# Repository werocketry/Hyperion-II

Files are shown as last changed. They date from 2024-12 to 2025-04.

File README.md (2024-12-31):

# Hyperion-II

This repository contains all the resources, designs, and analyses for the Hyperion-II rocket project. It is organized into several folders, each dedicated to a specific aspect of the project. Below is a breakdown of the repository structure and its contents.

## Repository Details

Click [here](DSS.md) to see the design summary sheet!

### Structure

```
Hyperion-II
├───cad
│   └───dwg
├───ork
│   └───outputs
├───rasAeroII
├───schematics
└───testing
   └───aero
```

### `cad/`

Contains the computer-aided design (CAD) files for Hyperion-II, including drawings and 3D models. The `dwg/` subfolder is specifically for detailed technical drawings.

### `ork/`

Holds all OpenRocket simulation files (`.ork`) and associated Python scripts that utilize [orlab](https://github.com/CameronBrooks11/orlab) for simulation analysis. The `outputs/` subfolder contains generated plots, text files, and sensitivity analyses derived from these simulations. Once you have Python and a valid Java release installed, install `orlab` using:

```
pip install orlab
```

For detailed installation instructions see [CameronBrooks11/orlab](https://github.com/CameronBrooks11/orlab).

### `rasAeroII/`

Placeholder for files related to RASAero II simulations.

### `schematics/`

Contains electronic schematics and related documentation for onboard systems.

### `testing/`

Documents all physical tests, including aerodynamics, electronics, and structural assessments. Each test has its own subfolder with details and results.

- **Key Subfolders**:
  - `2024-11-24_compression_al_couplers/`: Contains data for aluminum coupler compression testing on the specified date.

## Contributing

Contributions are welcome! Please fork the repository, make your changes, and submit a pull request. Ensure you adhere to the coding standards and provide detailed documentation for any new scripts or analyses.

## License

This project is licensed under the terms of the [MIT License](LICENSE).

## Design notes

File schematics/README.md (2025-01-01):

# schematics

This is where the source files and most recent exports will be stored and historical export versions on teams.

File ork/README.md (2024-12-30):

# ork

This is where our OpenRocket simulations go. The `.py` scripts leverage [orlab](https://github.com/CameronBrooks11/orlab) to run OpenRocket via Python. Doing this allows us to build and test our rocket using the OpenRocket application GUI, then use code to automate and enhance the analysis.

By scripting with `orlab`, we can:

- Run simulations programmatically, enabling batch testing and parameter sweeps.
- Extract detailed flight data and events for further processing.
- Generate custom plots and outputs that are not natively available in OpenRocket.
- Integrate OpenRocket data into larger workflows or other engineering tools.

The `outputs` folder contains images and text files generated by the scripts, including:

- Flight performance plots such as thrust, velocity, and altitude over time.
- Key metrics like rail exit velocity, average descent velocities, and ground impact conditions.
- Summarized event logs detailing critical moments in the flight, such as apogee, recovery deployments, and ground hit.

This approach ensures that we can efficiently analyze and refine our rocket designs while keeping a comprehensive record of simulation results for future reference.

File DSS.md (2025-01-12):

# Design Summary Sheet

This document outlines the design and components of the rocket, organized by subteam and section, detailing the contributions of each.

## By Subteam

- **Aero**

  - Nose cone (88cm)
    - COTS 14cm (5.5") diameter, 5.5:1 Von Karman, fibreglass
      - Machined aluminium tip
      - [madcowrocketry - 5.5 nose cone with metal tip](https://www.madcowrocketry.com/fiberglass-5-5-filament-wound-metal-tip-select-shape/)
      - Length of curvature 74cm + length of flat portion 14cm
  - CF Tubes
    - Main chute bay tube (39cm)
    - Airbrakes/drogue chute bay tube (56cm)
    - Engine tube (61cm)
  - Fibreglass tubes
    - Avionics bay tube (33cm)
    - For areas that require RF permeability
  - Aluminum Bulkheads
    - Diameter 13.244cm
    - Thickness 1.5cm
  - Fins
    - Tip to tip attachment
    - Fins made using a composite sandwich:
      - Foam core as the inner base
      - Intermediate layers of glass fibre
      - Outer layers of carbon fibre
    - Specifications:
      - Root chord: 33.1cm
      - Tip chord: 13.95cm
      - Span: 13.5cm
      - Sweep angle: 35.35 degrees

- **Airbrakes**

  - Airbrakes flaps cut from body tube
    - 3 flaps extending radially
    - Flaps mounted on PETG supports with fore edge on a hinge and the aft edge connected to PETG push rod
    - Lead screw driven by DC motor actuates push rods
    - DC motor with gearbox operated using custom flight controller powered by 18650 Li-ion cells

- **Avionics**

  - Dual deployment with redundant electronics
    - Primary: Featherweight Blue Raven + Featherweight GPS
    - Redundant: Altus Metrum Telemega (integrated GPS)
  - Two-sided "sled" style avionics bay made of polycarbonate sheets and 3D printed PETG parts

- **Payload**

  - 3U Payload
    - 9.6cm x 9.6cm x 30cm
      - Needs to be undersized from 10cm profile to fit existing nosecone
    - CubeSat form factor frame made from aluminium
    - Contains the SRAD flight computer
    - Ballast to reach target mass (inert, possibly a pioreactor)
    - 4000g (8.818lbs) (subject to change)

- **Propulsion**

  - 3G 96mm CTI hardware
    - M2505 as chosen reload
      - Performance: Total impulse of 7450.00 N·s, average thrust of 2491.02 N, and maximum thrust of 2952.61 N over a 3.00-second burn time
      - Specifications: Dimensions of 98.0 mm x 579.0 mm, with a propellant mass of 3.339 kg and casing mass of 2.866 kg
      - Ignition System: Dual-headed boron igniter
    - Alternatives: M1290, M1520

- **Recovery**
  - Main chute
    - 244cm (96") ripstop nylon main chute
      - Six 30cm shroud lines
  - Drogue chute
    - 61cm (24") ripstop nylon drogue chute
      - Six 30cm shroud lines
  - Kevlar shock cords

## By Section

- **Nose cone (88cm)**

  - COTS 14cm (5.5") diameter, 5.5:1 Von Karman, fibreglass
    - Machined aluminium tip
    - [madcowrocketry - 5.5 nose cone with metal tip](https://www.madcowrocketry.com/fiberglass-5-5-filament-wound-metal-tip-select-shape/)
    - Length of curvature 74cm + length of flat portion 14cm
  - 3U Payload
    - 9.6cm x 9.6cm x 30cm
    - CubeSat form factor frame made from aluminium
    - Contains SRAD flight computer and ballast
    - 4000g (8.818lbs)
  - Aluminum Bulkhead
    - Diameter 13.244cm
    - Thickness 1.5cm

- **Main chute bay (39cm)**

  - Carbon fibre tube
  - 244cm (96") ripstop nylon main chute
    - Six 30cm shroud lines

- **Avionics bay (33cm)**

  - Fibreglass tube (chosen over CF for RF permeability)
  - Dual deployment with redundant electronics
    - Primary: Featherweight Blue Raven + Featherweight GPS
    - Redundant: Altus Metrum Telemega (integrated GPS)

- **Airbrakes - drogue chute bay (56cm)**

  - Carbon fibre tube
  - 61cm (24") ripstop nylon drogue chute
    - Six 30cm shroud lines
  - Airbrakes flaps cut from body tube
    - 3 flaps extending radially
    - Flaps mounted on PETG supports with fore edge on a hinge and the aft edge connected to PETG push rod
    - Lead screw driven by DC motor actuates push rods
    - DC motor operated using custom flight controller powered by 18650 Li-ion cells

- **Engine tube (61cm)**
  - Carbon fibre tube
  - 3G 96mm CTI hardware
    - M2505 as chosen reload
      - Performance: Total impulse of 7450.00 N·s, average thrust of 2491.02 N, and maximum thrust of 2952.61 N over a 3.00-second burn time
      - Specifications: Dimensions of 98.0 mm x 579.0 mm, with a propellant mass of 3.339 kg and casing mass of 2.866 kg
      - Ignition System: Dual-headed boron igniter
      - Alternatives: M1290, M1520
  - Tip to tip attachment of fins
    - Fins made using a composite sandwich consisting of foam core as the inner base followed by intermediate layers of glass fibre followed by outer layers of carbon fibre
    - Specifications: Root chord of 33.1cm, tip chord of 13.95cm, span of 13.5cm, and sweep angle of 35.35 degrees

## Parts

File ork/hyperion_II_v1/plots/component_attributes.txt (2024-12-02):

List of all components with their attributes:

Component 1:
  Name: HyperionIIV1
  Type: Rocket
  Mass: 0.0 kg
  Length: 2.7974218000000004 m
  Diameter: Not Available
  Reference Area: Not Available

--------------------------------------------------

Component 2:
  Name: Sustainer
  Type: AxialStage
  Mass: 0.0 kg
  Length: 2.7720218 m
  Diameter: Not Available
  Reference Area: Not Available

--------------------------------------------------

Component 3:
  Name: Nose Cone
  Type: NoseCone
  Mass: 0.636 kg
  Length: 0.742 m
  Diameter: Not Available
  Reference Area: Not Available

--------------------------------------------------

Component 4:
  Name: Nosecone - Flat Portion
  Type: BodyTube
  Mass: 0.3 kg
  Length: 0.1397 m
  Diameter: Not Available
  Reference Area: Not Available

--------------------------------------------------

Component 5:
  Name: Payload
  Type: MassComponent
  Mass: 3.992 kg
  Length: 0.3 m
  Diameter: Not Available
  Reference Area: Not Available

--------------------------------------------------

Component 6:
  Name: Main Chute Bay
  Type: BodyTube
  Mass: 0.335 kg
  Length: 0.39032179999999994 m
  Diameter: Not Available
  Reference Area: Not Available

--------------------------------------------------

Component 7:
  Name: Nosecone-Main Coupler
  Type: TubeCoupler
  Mass: 0.312 kg
  Length: 0.28 m
  Diameter: Not Available
  Reference Area: Not Available

--------------------------------------------------

Component 8:
  Name: Nosecone-Main Bulkhead
  Type: Bulkhead
  Mass: 0.5535 kg
  Length: 0.015 m
  Diameter: Not Available
  Reference Area: Not Available

--------------------------------------------------

Component 9:
  Name: Main Parachute
  Type: Parachute
  Mass: 1.044 kg
  Length: 0.2286 m
  Diameter: 2.4383999999999997 m
  Reference Area: Not Available

--------------------------------------------------

Component 10:
  Name: Deployable Payload
  Type: MassComponent
  Mass: 1.5 kg
  Length: 0.1 m
  Diameter: Not Available
  Reference Area: Not Available

--------------------------------------------------

Component 11:
  Name: Deployable Parachute
  Type: Parachute
  Mass: 0.377 kg
  Length: 0.115824 m
  Diameter: 0.6095999999999999 m
  Reference Area: Not Available

--------------------------------------------------

Component 12:
  Name: Av Bay Body Tube
  Type: BodyTube
  Mass: 0.28600000000000003 kg
  Length: 0.32799999999999996 m
  Diameter: Not Available
  Reference Area: Not Available

--------------------------------------------------

Component 13:
  Name: Avionics
  Type: MassComponent
  Mass: 0.77 kg
  Length: 0.298 m
  Diameter: Not Available
  Reference Area: Not Available

--------------------------------------------------

Component 14:
  Name: Main-Avionics Coupler
  Type: TubeCoupler
  Mass: 0.244 kg
  Length: 0.28 m
  Diameter: Not Available
  Reference Area: Not Available

--------------------------------------------------

Component 15:
  Name: Avionics-Main Bulkhead
  Type: Bulkhead
  Mass: 0.5535 kg
  Length: 0.015 m
  Diameter: Not Available
  Reference Area: Not Available

--------------------------------------------------

Component 16:
  Name: Airbrakes-Drogue Body Tube
  Type: BodyTube
  Mass: 0.359 kg
  Length: 0.56 m
  Diameter: Not Available
  Reference Area: Not Available

--------------------------------------------------

Component 17:
  Name: Avionics-Drogue Coupler
  Type: TubeCoupler
  Mass: 0.244 kg
  Length: 0.28 m
  Diameter: Not Available
  Reference Area: Not Available

--------------------------------------------------

Component 18:
  Name: Drogue-Avionics Bulkhead
  Type: Bulkhead
  Mass: 0.5535 kg
  Length: 0.015 m
  Diameter: Not Available
  Reference Area: Not Available

--------------------------------------------------

Component 19:
  Name: Drogue Parachute
  Type: Parachute
  Mass: 0.377 kg
  Length: 0.15239999999999998 m
  Diameter: 0.6095999999999999 m
  Reference Area: Not Available

--------------------------------------------------

Component 20:
  Name: Airbrakes-Drogue Bulkhead
  Type: Bulkhead
  Mass: 0.5967 kg
  Length: 0.015 m
  Diameter: Not Available
  Reference Area: Not Available

--------------------------------------------------

Component 21:
  Name: Airbrakes
  Type: MassComponent
  Mass: 0.663 kg
  Length: 0.23 m
  Diameter: Not Available
  Reference Area: Not Available

--------------------------------------------------

Component 22:
  Name: Additional Mass
  Type: MassComponent
  Mass: 1.0 kg
  Length: 0.025 m
  Diameter: Not Available
  Reference Area: Not Available

--------------------------------------------------

Component 23:
  Name: Engine Tube
  Type: BodyTube
  Mass: 0.733 kg
  Length: 0.612 m
  Diameter: Not Available
  Reference Area: Not Available

--------------------------------------------------

Component 24:
  Name: Airbrakes-Engine Coupler
  Type: TubeCoupler
  Mass: 0.312 kg
  Length: 0.32 m
  Diameter: Not Available
  Reference Area: Not Available

--------------------------------------------------

Component 25:
  Name: Engine Bulkhead
  Type: Bulkhead
  Mass: 0.5562 kg
  Length: 0.015 m
  Diameter: Not Available
  Reference Area: Not Available

--------------------------------------------------

Component 26:
  Name: Centering Ring
  Type: CenteringRing
  Mass: 0.029157624072791443 kg
  Length: 0.004762499999999999 m
  Diameter: Not Available
  Reference Area: Not Available

--------------------------------------------------

Component 27:
  Name: Centering Ring
  Type: CenteringRing
  Mass: 0.029157624072791443 kg
  Length: 0.004762499999999999 m
  Diameter: Not Available
  Reference Area: Not Available

--------------------------------------------------

Component 28:
  Name: Freeform fin set #1
  Type: FreeformFinSet
  Mass: 0.60946425 kg
  Length: 0.330708 m
  Diameter: Not Available
  Reference Area: Not Available

--------------------------------------------------

Component 29:
  Name: Inner Motor Tube
  Type: InnerTube
  Mass: 0.08746076137869509 kg
  Length: 0.55 m
  Diameter: Not Available
  Reference Area: Not Available

--------------------------------------------------

Component 30:
  Name: Launch lug
  Type: LaunchLug
  Mass: 0.0067 kg
  Length: 0.03 m
  Diameter: Not Available
  Reference Area: Not Available

--------------------------------------------------

Component 31:
  Name: Launch lug
  Type: LaunchLug
  Mass: 0.0067 kg
  Length: 0.03 m
  Diameter: Not Available
  Reference Area: Not Available

--------------------------------------------------

Component 32:
  Name: Thrust Plate
  Type: MassComponent
  Mass: 0.242 kg
  Length: 0.028575 m
  Diameter: Not Available
  Reference Area: Not Available

--------------------------------------------------

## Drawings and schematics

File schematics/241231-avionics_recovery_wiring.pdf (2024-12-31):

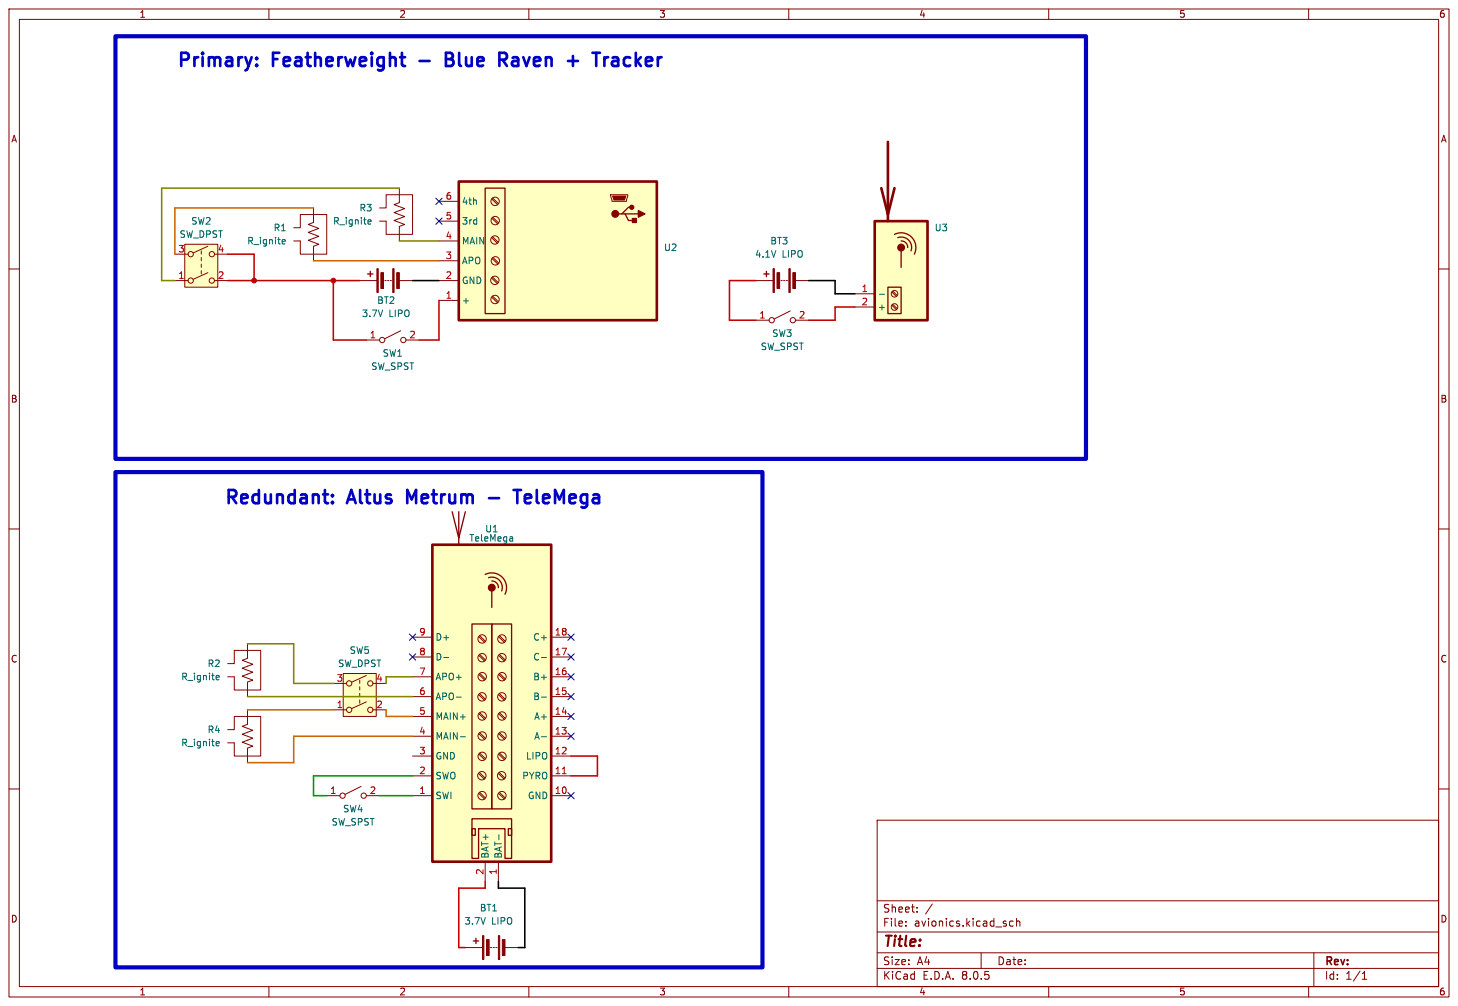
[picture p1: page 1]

2 SWO 2 GND 3 MAIN- 4 MAIN+ 5 APO- 6 APO+ 7 D- 8 D+ 9 U1 TeleMega R2 R_ignite BT1

Id: 1/1 Title: File: avionics.kicad_sch Sheet: / R4 R_ignite

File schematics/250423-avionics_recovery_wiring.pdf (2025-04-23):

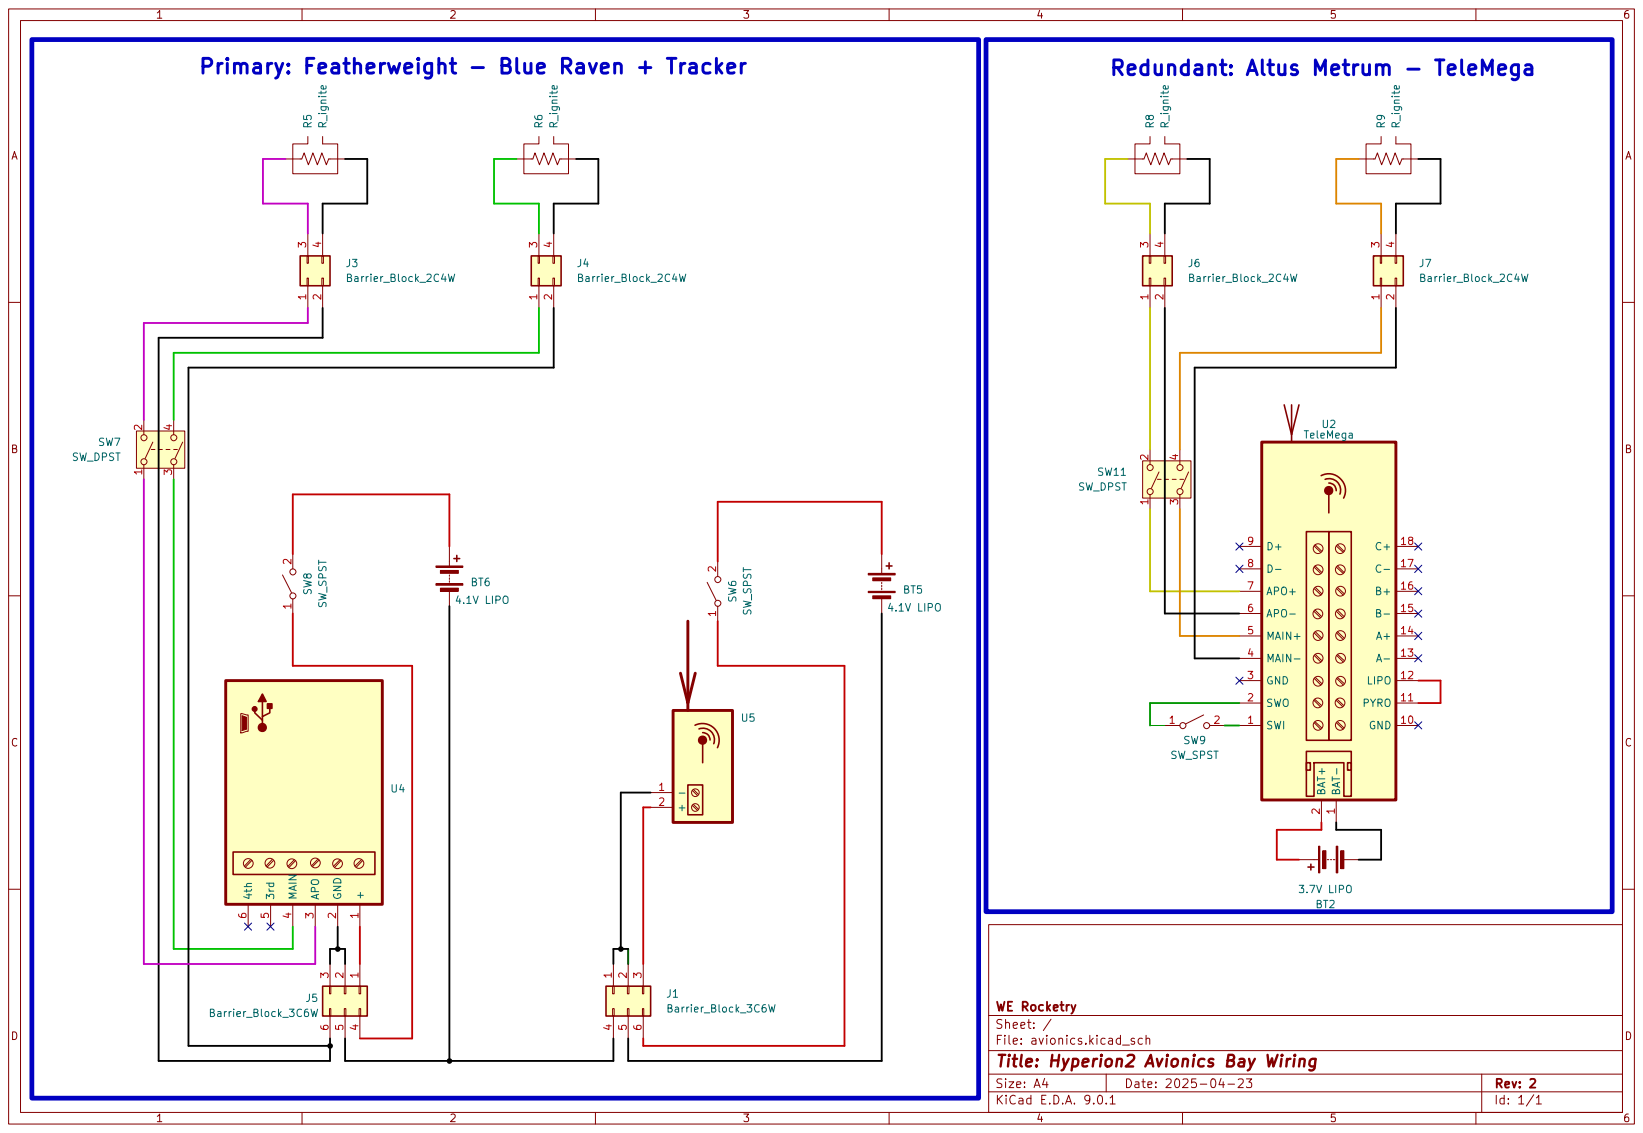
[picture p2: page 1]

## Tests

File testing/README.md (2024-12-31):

# Testing

| Test | Description | Methods & Facilities Available | Procedure and Methodology | Subteam | Estimated Deliverable Dates |
| --- | --- | --- | --- | --- | --- |
| **Al Coupler Compression Test** | Assess structural integrity of ring couplers under compression. | Utilize mechanical tester to emulate forces exerted by CF body tubes on aluminum ring couplers. | [README](./2024-11-24_compression_al_couplers/README.md) | Aero | Completed on 2024-11-24 |
| **Ejection Charge Test** | Verify functionality of ejection charges under controlled conditions. | Conduct outdoor tests to assess charge performance. | [README](./ejection-charge-test/README.md) | Recovery | January 2025 |
| **3-Point Bend Test for Couplers** | Evaluate flexural strength and stiffness of couplers. | Use mechanical testing equipment to apply bending loads. | [README](./3-point-bend-test/README.md) | Aero | January 2025 |
| **Tube Compression Test** | Determine compressive strength and failure modes of body tubes. | Employ mechanical tester to simulate axial loads. | [README](./tube-compression-test/README.md) | Aero | January 2025 |
| **Payload Frame Compression Test** | Assess payload frame's ability to withstand compressive forces. | Utilize mechanical testing equipment to simulate launch stresses. | [README](./payload-frame-compression-test/README.md) | Payload | January 2025 |
| **Airbrakes Electromechanical Actuation Test** | Evaluate performance of airbrake actuation mechanism under various loads.  | Test under maximum dynamic and static loads; measure performance metrics. | [README](./airbrakes-actuation-test/README.md) | Avionics | February 2025 |
| **Payload SRAD Flight Computer Benchtop System Test** | Validate functionality of flight computer in controlled environment. | Set up flight computer with necessary peripherals; use test bench for simulation. | [README](./flight-computer-benchtop-test/README.md) | Payload | February 2025 |
| **Payload SRAD Flight Computer Dry Test with Model Rocket** | Test flight computer's performance in a simulated flight environment. | Integrate flight computer into model rocket; conduct ground tests. | [README](./flight-computer-dry-test/README.md) | Payload | March 2025 |
| **Avionics Telemetry Range Test** | Assess communication range and reliability of telemetry system. | Drive to remote locations to test signal strength and data transmission. | [README](./telemetry-range-test/README.md) | Avionics | March 2025 |
| **Full-Scale Ejection Test** | Simulate actual ejection scenario to validate recovery system performance. | Mount airframe vertically; conduct full-scale ejection simulation. | [README](./full-scale-ejection-test/README.md) | Recovery | March 2025 |
| **Full Test Launch** | Conduct final launch to validate all systems under flight conditions. | Perform integrated launch with all systems operational. | [README](./full-test-launch/README.md) | All | Late April / May 2025 |

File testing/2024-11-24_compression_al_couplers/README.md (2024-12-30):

# Notes from 2024-11-24_compression_al_couplers

- Tested both Prometheus aluminum couplers in compression
- Force was transfered from one side of the load cell through blue tube, then through the ledge that sticks out from the coupler's main cylindrical body, and then through blue tube again to the other side of the load cell
- The vast majority of the strain was due to the blue tube straining, so that data won't tell you about the couplers (and don't try to back-calculate that out from the data, as the blue tube wasn't cut that well, was quite uneven, and for the second loading slipped off the coupler). As such, the data itself isn't much use beyond saying the max load they took
- Neither coupler sustained any visible damage
- First coupler loading was manually stopped at 2500 N, as we expect flight loads to be well under that
- Second loading was stopped when edge of the blue tube slipped around part of the coupler. Coupler took 1700 N before the test was stopped. We expect that to be significantly less than the upper coupler will sustain in flight

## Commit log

2024-12-02 Track large files with Git LFS
2024-12-02 Added .gitignore for KiCAD, SolidWorks, and general files
2024-12-30 update testing with some charts for al couplers
2024-12-31 created avionics schematics and exported as pdf
    [avionics.kicad_sch]
2025-04-23 updated av bay schematic
    [avionics.kicad_sch]
2025-04-23 fixed schem switch
    [avionics.kicad_sch]
2025-09-21 upload flight data as submitted to LC
    [2025-08-21_primary_blueraven_lr.csv, 2025-08-21_primary_blueraven_lr.events.csv, 2025-08-21_primary_blueraven_lr.events_no_thresh.csv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]
